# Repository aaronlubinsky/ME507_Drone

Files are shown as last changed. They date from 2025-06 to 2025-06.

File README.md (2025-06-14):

# ME-507 Drone Project



## Overview
This is the documentation for a quadcopter design by Aaron Lubisnky and Dane Carroll. This project was taken on and guided by Cal Poly's ME507 course (Graduate Mechanical Control Systems Design) and instructed by lecturer, Charlie Refvem.

The drone has a custom designed and 3D printed frame. It has been designed to operate using a custom PCB including an onboard STM2F411CEU6 MCU and BNO055 IMU. Though, currently uses a Blackpill development board and Bosch BN055 development board due to in house PCB manufacturing failures. The arming sequence is tailored towards ReadyTosky ESCs and the bluetooth module (HC05) is intended to interact with a PC running a custom python script for drone control and plotting blackbox data.

## Hardware
The drone’s frame, fabricated using 3D printing technology, is lightweight yet robust, providing a stable platform for four brushless motors, each controlled by an individual ReadyToSky electronic speed controller. Power is supplied by a 3s or 4s LiPo battery, distributed through a 4-channel power distribution board to ensure consistent voltage delivery to all components. At the core of the electronics system is an STM32F411 development board (Blackpill), which serves as the primary microcontroller for processing sensor data and executing control algorithms. Orientation sensing is achieved using an Adafruit BNO055 IMU module, which provides 9-axis data (accelerometer, gyroscope, and magnetometer) in fusion mode for accurate roll, pitch, and yaw measurements. Wireless communication is enabled by an HC-05 Bluetooth module, allowing the drone to receive commands from a ground station and transmit blackbox data for real-time monitoring. Status LEDs are integrated to provide visual feedback on the drone’s operational state, such as arming status and error conditions. While the current setup relies on development boards due to PCB manufacturing issues, the design is optimized for a future transition to a custom PCB integrating the STM32F411CEU6 and BNO055, which will reduce size, weight, and potential points of failure.

**Hardware Components:**
- STM32F4 Development Board
- BNO055 IMU Module
- HC05 Bluetooth Module
- 4x Electronic Speed Controllers (ESCs)
- 4x 3 Phase Brushless Motors
- 4-channel Power Distribution Board
- 3s/4s Battery
- Status LEDs

## Software Implementation
The software for the ME-507 Drone Project is a sophisticated flight control system that integrates real-time sensor processing, control algorithms, and wireless communication. The core of the system runs on the STM32F411 development board, utilizing a finite state machine to manage the drone’s operational states, including initialization, sensor calibration, ESC arming, PID control updates, and blackbox data transmission. The flight control is implemented using a 3-axis PID control loop, with independent controllers for roll, pitch, and yaw to maintain stable flight. The BNO055 IMU operates in fusion mode, combining accelerometer, gyroscope, and magnetometer data to provide accurate orientation measurements. Motor control is achieved by generating PWM signals using the STM32’s hardware timers, ensuring precise and responsive adjustments to the brushless motors. Commands are received wirelessly from an Xbox controller via the HC-05 Bluetooth module, with a custom Python script running on a PC ground station parsing joystick inputs and mapping them to setpoints for angle (roll, pitch, yaw) and throttle. This Python script also handles blackbox data logging, enabling post-flight analysis of flight dynamics. The software is designed for modularity, allowing for easy integration of advanced control algorithms or additional sensors in future iterations. 

## Modeling and Tuning


The control system design for the ME-507 Drone Project relied on a dynamic model of the quadcopter to inform the tuning of its PID controllers. The PID tuning process involved a combination of analytical and empirical methods to balance responsiveness and stability. Initial tuning parameters were derived from the dynamic model, focusing on the roll and pitch dynamics, which were tested independently using step-response experiments. These tests involved applying controlled inputs to the drone and measuring its response via the BNO055 IMU, with data logged for pitch, roll, and yaw angles. The logged data was visualized using the Python ground station software, allowing the team to analyze overshoot, settling time, and steady-state error. Iterative tuning was performed by adjusting the proportional, integral, and derivative gains to minimize oscillations and improve tracking performance. 



## Documentation
The complete codebase is documented using Doxygen. Visit the hosted documentation at:

[aaronlubinsky.github.io/ME507_Drone](https://aaronlubinsky.github.io/ME507_Drone/html/index.html)

## Future Improvements
To advance this project, several key improvements are planned to enhance its functionality, compactness, and performance. A primary goal is transitioning from the current Blackpill development board and Bosch BNO055 development board to a custom-designed PCB integrating the STM32F411CEU6 microcontroller and BNO055 IMU. This will streamline the electronics, reduce weight, and improve reliability by eliminating the dependency on external development boards, addressing the challenges faced with in-house PCB manufacturing failures. Additionally, the Python-based ground station software will be enhanced to include a more robust user interface, featuring real-time plotting of critical flight parameters such as orientation, throttle, and control effort, alongside interactive tuning capabilities for PID gains. Another potential upgrade would be integrating a more robust wireless communication protocol, such as Wi-Fi or a dedicated RF module, to replace the HC-05 Bluetooth module, which would increase range and data throughput.

## Acknowledgments
We thank Lecturer Charlie Refvem for his guidance and Cal Poly's ME-507 course for providing the framework to develop this project.

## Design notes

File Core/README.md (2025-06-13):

# ME-507 Drone Project



## Overview
This is the documentation for a quadcopter design by Aaron Lubisnky and Dane Carroll. This project was taken on and guided by Cal Poly's ME507 course (Graduate Mechanical Control Systems Design) and instructed by lecturer, Charlie Refvem.

The drone has a custom designed and 3D printed frame. It has been designed to operate using a custom PCB including an onboard STM2F411CEU6 MCU and BNO055 IMU. Though, currently uses a Blackpill development board and Bosch BN055 development board due to in house PCB manufacturing failures. The arming sequence is tailored towards ReadyTosky ESCs and the bluetooth module (HC05) is intended to interact with a PC running a custom python script for drone control and plotting blackbox data.

## Hardware
The drone consists of a custom electronics system powered by an STM32F411 development board. It uses a 3D-printed frame to house four brushless motors, ESCs, a power distribution board, and a LiPo battery. A 9-axis IMU is used for orientation sensing, and an HC-05 Bluetooth module allows wireless communication. 

**Hardware Components:**
- STM32F4 Development Board
- BNO055 IMU Module
- HC05 Bluetooth Module
- 4x Electronic Speed Controllers (ESCs)
- 4x 3 Phase Brushless Motors
- 4-channel Power Distribution Board
- 3s/4s Battery
- Status LEDs

## Software Implementation
The flight control system is built using a 3-axis PID loop, with separate PID controllers for roll, pitch, and yaw. Commands are received wirelessly from an Xbox controller via Bluetooth, with a Python script parsing joystick input and mapping it to setpoints for angle and throttle. The STM32’s main loop is structured as a finite state machine with stages for initialization, calibration, ESC arming, PID updates, and sending blackbox data. Orientation measurements are handled using the BNO055 9 axis IMU in fusion mode. Motor outputs are updated every control cycle, with PWM signals generated using STM32 timers. 

## Modeling and Tuning
[Insert Image of Block Diagram]

A dynamic model of the drone was used to derive tuning parameters for the PID loops. Control effort and responsiveness were balanced using empirical tuning and log analysis. Pitch and roll dynamics were first tuned independently using step-response testing. Sensor data such as pitch, roll, and yaw angles were logged and plotted to visualize control performance. This allowed iterative tuning to reduce overshoot and steady-state error.



## Documentation
The complete codebase is documented using Doxygen. Visit the hosted documentation at:

https://aaronlubinsky.github.io/ME507_Drone/

## Future Improvements
Transition to the custom PCB with integrated STM32F411CEU6 and BNO055 for a compact design.
Enhance Python ground station software with real-time plotting and tuning interfaces.
Implement advanced control algorithms (e.g., model predictive control) for improved stability.
To advance this project, several key improvements are planned to enhance its functionality, compactness, and performance. A primary goal is transitioning from the current Blackpill development board and Bosch BNO055 development board to a custom-designed PCB integrating the STM32F411CEU6 microcontroller and BNO055 IMU. This will streamline the electronics, reduce weight, and improve reliability by eliminating the dependency on external development boards, addressing the challenges faced with in-house PCB manufacturing failures. Additionally, the Python-based ground station software will be enhanced to include a more robust user interface, featuring real-time plotting of critical flight parameters such as orientation, throttle, and control effort, alongside interactive tuning capabilities for PID gains. Another potential upgrade would be integrating a more robust wireless communication protocol, such as Wi-Fi or a dedicated RF module, to replace the HC-05 Bluetooth module, which would increase range and data throughput.

## Acknowledgments
We thank Lecturer Charlie Refvem for his guidance and Cal Poly's ME-507 course for providing the framework to develop this project.

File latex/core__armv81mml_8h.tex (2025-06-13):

\doxysection{Drivers/\+CMSIS/\+Include/core\+\_\+armv81mml.h File Reference}
\hypertarget{core__armv81mml_8h}{}\label{core__armv81mml_8h}\index{Drivers/CMSIS/Include/core\_armv81mml.h@{Drivers/CMSIS/Include/core\_armv81mml.h}}

CMSIS Armv8.\+1-\/M Mainline Core Peripheral Access Layer Header File.  

{\ttfamily \#include $<$stdint.\+h$>$}\newline
{\ttfamily \#include "{}cmsis\+\_\+version.\+h"{}}\newline
{\ttfamily \#include "{}cmsis\+\_\+compiler.\+h"{}}\newline
{\ttfamily \#include "{}mpu\+\_\+armv8.\+h"{}}\newline
\doxysubsubsection*{Classes}
\begin{DoxyCompactItemize}
\item 
union \mbox{\hyperlink{union_a_p_s_r___type}{APSR\+\_\+\+Type}}
\begin{DoxyCompactList}\small\item\em Union type to access the Application Program Status Register (APSR). \end{DoxyCompactList}\item 
union \mbox{\hyperlink{union_i_p_s_r___type}{IPSR\+\_\+\+Type}}
\begin{DoxyCompactList}\small\item\em Union type to access the Interrupt Program Status Register (IPSR). \end{DoxyCompactList}\item 
union \mbox{\hyperlink{unionx_p_s_r___type}{x\+PSR\+\_\+\+Type}}
\begin{DoxyCompactList}\small\item\em Union type to access the Special-\/\+Purpose Program Status Registers (x\+PSR). \end{DoxyCompactList}\item 
union \mbox{\hyperlink{union_c_o_n_t_r_o_l___type}{CONTROL\+\_\+\+Type}}
\begin{DoxyCompactList}\small\item\em Union type to access the Control Registers (CONTROL). \end{DoxyCompactList}\item 
struct \mbox{\hyperlink{struct_n_v_i_c___type}{NVIC\+\_\+\+Type}}
\begin{DoxyCompactList}\small\item\em Structure type to access the Nested Vectored Interrupt Controller (NVIC). \end{DoxyCompactList}\item 
struct \mbox{\hyperlink{struct_s_c_b___type}{SCB\+\_\+\+Type}}
\begin{DoxyCompactList}\small\item\em Structure type to access the System Control Block (SCB). \end{DoxyCompactList}\item 
struct \mbox{\hyperlink{struct_s_cn_s_c_b___type}{SCn\+SCB\+\_\+\+Type}}
\begin{DoxyCompactList}\small\item\em Structure type to access the System Control and ID Register not in the SCB. \end{DoxyCompactList}\item 
struct \mbox{\hyperlink{struct_sys_tick___type}{Sys\+Tick\+\_\+\+Type}}
\begin{DoxyCompactList}\small\item\em Structure type to access the System Timer (Sys\+Tick). \end{DoxyCompactList}\item 
struct \mbox{\hyperlink{struct_i_t_m___type}{ITM\+\_\+\+Type}}
\begin{DoxyCompactList}\small\item\em Structure type to access the Instrumentation Trace Macrocell Register (ITM). \end{DoxyCompactList}\item 
struct \mbox{\hyperlink{struct_d_w_t___type}{DWT\+\_\+\+Type}}
\begin{DoxyCompactList}\small\item\em Structure type to access the Data Watchpoint and Trace Register (DWT). \end{DoxyCompactList}\item 
struct \mbox{\hyperlink{struct_t_p_i___type}{TPI\+\_\+\+Type}}
\begin{DoxyCompactList}\small\item\em Structure type to access the Trace Port Interface Register (TPI). \end{DoxyCompactList}\item 
struct \mbox{\hyperlink{struct_m_p_u___type}{MPU\+\_\+\+Type}}
\begin{DoxyCompactList}\small\item\em Structure type to access the Memory Protection Unit (MPU). \end{DoxyCompactList}\item 
struct \mbox{\hyperlink{struct_f_p_u___type}{FPU\+\_\+\+Type}}
\begin{DoxyCompactList}\small\item\em Structure type to access the Floating Point Unit (FPU). \end{DoxyCompactList}\item 
struct \mbox{\hyperlink{struct_core_debug___type}{Core\+Debug\+\_\+\+Type}}
\begin{DoxyCompactList}\small\item\em Structure type to access the Core Debug Register (Core\+Debug). \end{DoxyCompactList}\item 
struct \mbox{\hyperlink{struct_d_c_b___type}{DCB\+\_\+\+Type}}
\begin{DoxyCompactList}\small\item\em Structure type to access the Debug Control Block Registers (DCB). \end{DoxyCompactList}\item 
struct \mbox{\hyperlink{struct_d_i_b___type}{DIB\+\_\+\+Type}}
\begin{DoxyCompactList}\small\item\em Structure type to access the Debug Identification Block Registers (DIB). \end{DoxyCompactList}\end{DoxyCompactItemize}
\doxysubsubsection*{Macros}
\begin{DoxyCompactItemize}
\item 
\Hypertarget{core__armv81mml_8h_a6e3093e3f8f78406fa3b2428052ab8e7}\label{core__armv81mml_8h_a6e3093e3f8f78406fa3b2428052ab8e7} 
\#define {\bfseries \+\_\+\+\_\+\+CORE\+\_\+\+ARMV81\+MML\+\_\+\+H\+\_\+\+GENERIC}
\end{DoxyCompactItemize}
\textbf{ }\par
\begin{DoxyCompactItemize}
\item 
\#define \mbox{\hyperlink{group___c_m_s_i_s___c_o_r_e_gac469528d210043c7bd3f12f0e6824766}{APSR\+\_\+\+N\+\_\+\+Pos}}~31U
\item 
\#define \mbox{\hyperlink{group___c_m_s_i_s___c_o_r_e_gadbc2cf55a026f661b53fadfcf822cef1}{APSR\+\_\+\+N\+\_\+\+Msk}}~(1UL $<$$<$ \mbox{\hyperlink{group___c_m_s_i_s___c_o_r_e_gac469528d210043c7bd3f12f0e6824766}{APSR\+\_\+\+N\+\_\+\+Pos}})
\item 
\#define \mbox{\hyperlink{group___c_m_s_i_s___c_o_r_e_ga3661286d108b1aca308d7445685eae3a}{APSR\+\_\+\+Z\+\_\+\+Pos}}~30U
\item 
\#define \mbox{\hyperlink{group___c_m_s_i_s___c_o_r_e_ga1deb4d1aa72bb83d1f79329406f15711}{APSR\+\_\+\+Z\+\_\+\+Msk}}~(1UL $<$$<$ \mbox{\hyperlink{group___c_m_s_i_s___c_o_r_e_ga3661286d108b1aca308d7445685eae3a}{APSR\+\_\+\+Z\+\_\+\+Pos}})
\item 
\#define \mbox{\hyperlink{group___c_m_s_i_s___c_o_r_e_ga6cf72aa6f09a168f9e5beda1a4a887b9}{APSR\+\_\+\+C\+\_\+\+Pos}}~29U
\item 
\#define \mbox{\hyperlink{group___c_m_s_i_s___c_o_r_e_ga6d47803fbad455bc10bd1ce59f2f335d}{APSR\+\_\+\+C\+\_\+\+Msk}}~(1UL $<$$<$ \mbox{\hyperlink{group___c_m_s_i_s___c_o_r_e_ga6cf72aa6f09a168f9e5beda1a4a887b9}{APSR\+\_\+\+C\+\_\+\+Pos}})
\item 
\#define \mbox{\hyperlink{group___c_m_s_i_s___c_o_r_e_gac62830f67679ccd11658c4172c3e6ea7}{APSR\+\_\+\+V\+\_\+\+Pos}}~28U
\item 
\#define \mbox{\hyperlink{group___c_m_s_i_s___c_o_r_e_ga33305d6701356bff6890b315fe8b5489}{APSR\+\_\+\+V\+\_\+\+Msk}}~(1UL $<$$<$ \mbox{\hyperlink{group___c_m_s_i_s___c_o_r_e_gac62830f67679ccd11658c4172c3e6ea7}{APSR\+\_\+\+V\+\_\+\+Pos}})
\item 
\#define \mbox{\hyperlink{group___c_m_s_i_s___c_o_r_e_ga298749e176f12827328bb7b92a6b2411}{APSR\+\_\+\+Q\+\_\+\+Pos}}~27U
\item 
\#define \mbox{\hyperlink{group___c_m_s_i_s___c_o_r_e_ga90ffd4ec4149c2f5dd7747c1533fb002}{APSR\+\_\+\+Q\+\_\+\+Msk}}~(1UL $<$$<$ \mbox{\hyperlink{group___c_m_s_i_s___c_o_r_e_ga298749e176f12827328bb7b92a6b2411}{APSR\+\_\+\+Q\+\_\+\+Pos}})
\item 
\#define \mbox{\hyperlink{group___c_m_s_i_s___c_o_r_e_ga722cb42b5c75af3e8909fac6fd40dfdc}{APSR\+\_\+\+GE\+\_\+\+Pos}}~16U
\item 
\#define \mbox{\hyperlink{group___c_m_s_i_s___c_o_r_e_ga8a3ecbc0ea2029462b0f4ce50e227db1}{APSR\+\_\+\+GE\+\_\+\+Msk}}~(0x\+FUL $<$$<$ \mbox{\hyperlink{group___c_m_s_i_s___c_o_r_e_ga722cb42b5c75af3e8909fac6fd40dfdc}{APSR\+\_\+\+GE\+\_\+\+Pos}})
\item 
\#define \mbox{\hyperlink{group___c_m_s_i_s___c_o_r_e_ga0e34027584d02c43811ae908a5ca9adf}{IPSR\+\_\+\+ISR\+\_\+\+Pos}}~0U
\item 
\#define \mbox{\hyperlink{group___c_m_s_i_s___c_o_r_e_gaf013a4579a64d1f21f56ea9f1b33ab56}{IPSR\+\_\+\+ISR\+\_\+\+Msk}}~(0x1\+FFUL /\texorpdfstring{$\ast$}{*}$<$$<$ \mbox{\hyperlink{group___c_m_s_i_s___c_o_r_e_ga0e34027584d02c43811ae908a5ca9adf}{IPSR\+\_\+\+ISR\+\_\+\+Pos}}\texorpdfstring{$\ast$}{*}/)
\item 
\#define \mbox{\hyperlink{group___c_m_s_i_s___c_o_r_e_ga031eb1b8ebcdb3d602d0b9f2ec82a7ae}{x\+PSR\+\_\+\+N\+\_\+\+Pos}}~31U
\item 
\#define \mbox{\hyperlink{group___c_m_s_i_s___c_o_r_e_gaf600f4ff41b62cf2f3b0a59b6d2e93d6}{x\+PSR\+\_\+\+N\+\_\+\+Msk}}~(1UL $<$$<$ \mbox{\hyperlink{group___c_m_s_i_s___c_o_r_e_ga031eb1b8ebcdb3d602d0b9f2ec82a7ae}{x\+PSR\+\_\+\+N\+\_\+\+Pos}})
\item 
\#define \mbox{\hyperlink{group___c_m_s_i_s___c_o_r_e_ga5869dd608eea73c80f0567d781d2230b}{x\+PSR\+\_\+\+Z\+\_\+\+Pos}}~30U
\item 
\#define \mbox{\hyperlink{group___c_m_s_i_s___c_o_r_e_ga907599209fba99f579778e662021c4f2}{x\+PSR\+\_\+\+Z\+\_\+\+Msk}}~(1UL $<$$<$ \mbox{\hyperlink{group___c_m_s_i_s___c_o_r_e_ga5869dd608eea73c80f0567d781d2230b}{x\+PSR\+\_\+\+Z\+\_\+\+Pos}})
\item 
\#define \mbox{\hyperlink{group___c_m_s_i_s___c_o_r_e_ga14adb79b91f6634b351a1b57394e2db6}{x\+PSR\+\_\+\+C\+\_\+\+Pos}}~29U
\item 
\#define \mbox{\hyperlink{group___c_m_s_i_s___c_o_r_e_ga21e2497255d380f956ca0f48d11d0775}{x\+PSR\+\_\+\+C\+\_\+\+Msk}}~(1UL $<$$<$ \mbox{\hyperlink{group___c_m_s_i_s___c_o_r_e_ga14adb79b91f6634b351a1b57394e2db6}{x\+PSR\+\_\+\+C\+\_\+\+Pos}})
\item 
\#define \mbox{\hyperlink{group___c_m_s_i_s___c_o_r_e_gae0cfbb394490db402623d97e6a979e00}{x\+PSR\+\_\+\+V\+\_\+\+Pos}}~28U
\item 
\#define \mbox{\hyperlink{group___c_m_s_i_s___c_o_r_e_gab07f94ed3b6ee695f5af719dc27995c2}{x\+PSR\+\_\+\+V\+\_\+\+Msk}}~(1UL $<$$<$ \mbox{\hyperlink{group___c_m_s_i_s___c_o_r_e_gae0cfbb394490db402623d97e6a979e00}{x\+PSR\+\_\+\+V\+\_\+\+Pos}})
\item 
\#define \mbox{\hyperlink{group___c_m_s_i_s___c_o_r_e_gaabb4178d50676a8f19cf8f727f38ace8}{x\+PSR\+\_\+\+Q\+\_\+\+Pos}}~27U
\item 
\#define \mbox{\hyperlink{group___c_m_s_i_s___c_o_r_e_ga133ac393c38559ae43ac36383e731dd4}{x\+PSR\+\_\+\+Q\+\_\+\+Msk}}~(1UL $<$$<$ \mbox{\hyperlink{group___c_m_s_i_s___c_o_r_e_gaabb4178d50676a8f19cf8f727f38ace8}{x\+PSR\+\_\+\+Q\+\_\+\+Pos}})
\item 
\#define \mbox{\hyperlink{group___c_m_s_i_s___c_o_r_e_gac5be1db1343f776ecd00f0a4ebe70a46}{x\+PSR\+\_\+\+IT\+\_\+\+Pos}}~25U
\item 
\#define \mbox{\hyperlink{group___c_m_s_i_s___c_o_r_e_ga6dc177aab488851bb3b98cf4b420141a}{x\+PSR\+\_\+\+IT\+\_\+\+Msk}}~(3UL $<$$<$ \mbox{\hyperlink{group___c_m_s_i_s___c_o_r_e_gac5be1db1343f776ecd00f0a4ebe70a46}{x\+PSR\+\_\+\+IT\+\_\+\+Pos}})
\item 
\#define \mbox{\hyperlink{group___c_m_s_i_s___c_o_r_e_ga98d801da9a49cda944f52aeae104dd38}{x\+PSR\+\_\+\+T\+\_\+\+Pos}}~24U
\item 
\#define \mbox{\hyperlink{group___c_m_s_i_s___c_o_r_e_ga30ae2111816e82d47636a8d4577eb6ee}{x\+PSR\+\_\+\+T\+\_\+\+Msk}}~(1UL $<$$<$ \mbox{\hyperlink{group___c_m_s_i_s___c_o_r_e_ga98d801da9a49cda944f52aeae104dd38}{x\+PSR\+\_\+\+T\+\_\+\+Pos}})
\item 
\#define \mbox{\hyperlink{group___c_m_s_i_s___c_o_r_e_gae2b0f3def0f378e9f1d10a4c727a064b}{x\+PSR\+\_\+\+GE\+\_\+\+Pos}}~16U
\item 
\#define \mbox{\hyperlink{group___c_m_s_i_s___c_o_r_e_ga967634e605d013e9b07002eca31f7903}{x\+PSR\+\_\+\+GE\+\_\+\+Msk}}~(0x\+FUL $<$$<$ \mbox{\hyperlink{group___c_m_s_i_s___c_o_r_e_gae2b0f3def0f378e9f1d10a4c727a064b}{x\+PSR\+\_\+\+GE\+\_\+\+Pos}})
\item 
\#define \mbox{\hyperlink{group___c_m_s_i_s___c_o_r_e_ga21bff245fb1aef9683f693d9d7bb2233}{x\+PSR\+\_\+\+ISR\+\_\+\+Pos}}~0U
\item 
\#define \mbox{\hyperlink{group___c_m_s_i_s___c_o_r_e_gadf8eed87e0081dfe1ef1c78a0ea91afd}{x\+PSR\+\_\+\+ISR\+\_\+\+Msk}}~(0x1\+FFUL /\texorpdfstring{$\ast$}{*}$<$$<$ \mbox{\hyperlink{group___c_m_s_i_s___c_o_r_e_ga21bff245fb1aef9683f693d9d7bb2233}{x\+PSR\+\_\+\+ISR\+\_\+\+Pos}}\texorpdfstring{$\ast$}{*}/)
\item 
\#define \mbox{\hyperlink{group___c_m_s_i_s___c_o_r_e_gac4eb493f7e00c0b286f6663b2554d5f1}{CONTROL\+\_\+\+SFPA\+\_\+\+Pos}}~3U
\item 
\#define \mbox{\hyperlink{group___c_m_s_i_s___c_o_r_e_gae1af7c6a3a6482a32ae290b66db3a3f8}{CONTROL\+\_\+\+SFPA\+\_\+\+Msk}}~(1UL $<$$<$ \mbox{\hyperlink{group___c_m_s_i_s___c_o_r_e_gac4eb493f7e00c0b286f6663b2554d5f1}{CONTROL\+\_\+\+SFPA\+\_\+\+Pos}})
\item 
\#define \mbox{\hyperlink{group___c_m_s_i_s___c_o_r_e_gac7018b59b07134c5363b33eb94918a58}{CONTROL\+\_\+\+FPCA\+\_\+\+Pos}}~2U
\item 
\#define \mbox{\hyperlink{group___c_m_s_i_s___c_o_r_e_gad20bb0212b2e1864f24af38d93587c79}{CONTROL\+\_\+\+FPCA\+\_\+\+Msk}}~(1UL $<$$<$ \mbox{\hyperlink{group___c_m_s_i_s___c_o_r_e_gac7018b59b07134c5363b33eb94918a58}{CONTROL\+\_\+\+FPCA\+\_\+\+Pos}})
\item 
\#define \mbox{\hyperlink{group___c_m_s_i_s___c_o_r_e_ga07eafc53e609895342c6a530e9d01310}{CONTROL\+\_\+\+SPSEL\+\_\+\+Pos}}~1U
\item 
\#define \mbox{\hyperlink{group___c_m_s_i_s___c_o_r_e_ga70b29840969b06909da21369b0b05b53}{CONTROL\+\_\+\+SPSEL\+\_\+\+Msk}}~(1UL $<$$<$ \mbox{\hyperlink{group___c_m_s_i_s___c_o_r_e_ga07eafc53e609895342c6a530e9d01310}{CONTROL\+\_\+\+SPSEL\+\_\+\+Pos}})
\item 
\#define \mbox{\hyperlink{group___c_m_s_i_s___c_o_r_e_ga51b95bc03ec0d815b459bde0b14a5908}{CONTROL\+\_\+n\+PRIV\+\_\+\+Pos}}~0U
\item 
\#define \mbox{\hyperlink{group___c_m_s_i_s___c_o_r_e_gaef3b20d77acb213338f89ce5e7bc36b0}{CONTROL\+\_\+n\+PRIV\+\_\+\+Msk}}~(1UL /\texorpdfstring{$\ast$}{*}$<$$<$ \mbox{\hyperlink{group___c_m_s_i_s___c_o_r_e_ga51b95bc03ec0d815b459bde0b14a5908}{CONTROL\+\_\+n\+PRIV\+\_\+\+Pos}}\texorpdfstring{$\ast$}{*}/)
\item 
\#define \mbox{\hyperlink{group___c_m_s_i_s___c_o_r_e_ga9eebe495e2e48d302211108837a2b3e8}{NVIC\+\_\+\+STIR\+\_\+\+INTID\+\_\+\+Pos}}~0U
\item 
\#define \mbox{\hyperlink{group___c_m_s_i_s___c_o_r_e_gae4060c4dfcebb08871ca4244176ce752}{NVIC\+\_\+\+STIR\+\_\+\+INTID\+\_\+\+Msk}}~(0x1\+FFUL /\texorpdfstring{$\ast$}{*}$<$$<$ \mbox{\hyperlink{group___c_m_s_i_s___c_o_r_e_ga9eebe495e2e48d302211108837a2b3e8}{NVIC\+\_\+\+STIR\+\_\+\+INTID\+\_\+\+Pos}}\texorpdfstring{$\ast$}{*}/)
\item 
\#define \mbox{\hyperlink{group___c_m_s_i_s___c_o_r_e_ga58686b88f94f789d4e6f429fe1ff58cf}{SCB\+\_\+\+CPUID\+\_\+\+IMPLEMENTER\+\_\+\+Pos}}~24U
\item 
\#define \mbox{\hyperlink{group___c_m_s_i_s___c_o_r_e_ga0932b31faafd47656a03ced75a31d99b}{SCB\+\_\+\+CPUID\+\_\+\+IMPLEMENTER\+\_\+\+Msk}}~(0x\+FFUL $<$$<$ \mbox{\hyperlink{group___c_m_s_i_s___c_o_r_e_ga58686b88f94f789d4e6f429fe1ff58cf}{SCB\+\_\+\+CPUID\+\_\+\+IMPLEMENTER\+\_\+\+Pos}})
\item 
\#define \mbox{\hyperlink{group___c_m_s_i_s___c_o_r_e_ga104462bd0815391b4044a70bd15d3a71}{SCB\+\_\+\+CPUID\+\_\+\+VARIANT\+\_\+\+Pos}}~20U
\item 
\#define \mbox{\hyperlink{group___c_m_s_i_s___c_o_r_e_gad358dfbd04300afc1824329d128b99e8}{SCB\+\_\+\+CPUID\+\_\+\+VARIANT\+\_\+\+Msk}}~(0x\+FUL $<$$<$ \mbox{\hyperlink{group___c_m_s_i_s___c_o_r_e_ga104462bd0815391b4044a70bd15d3a71}{SCB\+\_\+\+CPUID\+\_\+\+VARIANT\+\_\+\+Pos}})
\item 
\#define \mbox{\hyperlink{group___c_m_s_i_s___c_o_r_e_gaf8b3236b08fb8e840efb682645fb0e98}{SCB\+\_\+\+CPUID\+\_\+\+ARCHITECTURE\+\_\+\+Pos}}~16U
\item 
\#define \mbox{\hyperlink{group___c_m_s_i_s___c_o_r_e_gafae4a1f27a927338ae9dc51a0e146213}{SCB\+\_\+\+CPUID\+\_\+\+ARCHITECTURE\+\_\+\+Msk}}~(0x\+FUL $<$$<$ \mbox{\hyperlink{group___c_m_s_i_s___c_o_r_e_gaf8b3236b08fb8e840efb682645fb0e98}{SCB\+\_\+\+CPUID\+\_\+\+ARCHITECTURE\+\_\+\+Pos}})
\item 
\#define \mbox{\hyperlink{group___c_m_s_i_s___c_o_r_e_ga705f68eaa9afb042ca2407dc4e4629ac}{SCB\+\_\+\+CPUID\+\_\+\+PARTNO\+\_\+\+Pos}}~4U
\item 
\#define \mbox{\hyperlink{group___c_m_s_i_s___c_o_r_e_ga98e581423ca016680c238c469aba546d}{SCB\+\_\+\+CPUID\+\_\+\+PARTNO\+\_\+\+Msk}}~(0x\+FFFUL $<$$<$ \mbox{\hyperlink{group___c_m_s_i_s___c_o_r_e_ga705f68eaa9afb042ca2407dc4e4629ac}{SCB\+\_\+\+CPUID\+\_\+\+PARTNO\+\_\+\+Pos}})
\item 
\#define \mbox{\hyperlink{group___c_m_s_i_s___c_o_r_e_ga3c3d9071e574de11fb27ba57034838b1}{SCB\+\_\+\+CPUID\+\_\+\+REVISION\+\_\+\+Pos}}~0U
\item 
\#define \mbox{\hyperlink{group___c_m_s_i_s___c_o_r_e_ga2ec0448b6483f77e7f5d08b4b81d85df}{SCB\+\_\+\+CPUID\+\_\+\+REVISION\+\_\+\+Msk}}~(0x\+FUL /\texorpdfstring{$\ast$}{*}$<$$<$ \mbox{\hyperlink{group___c_m_s_i_s___c_o_r_e_ga3c3d9071e574de11fb27ba57034838b1}{SCB\+\_\+\+CPUID\+\_\+\+REVISION\+\_\+\+Pos}}\texorpdfstring{$\ast$}{*}/)
\item 
\#define \mbox{\hyperlink{group___c_m_s_i_s___c_o_r_e_gac180386fac3a5701e6060084dacd003a}{SCB\+\_\+\+ICSR\+\_\+\+PENDNMISET\+\_\+\+Pos}}~31U
\item 
\#define \mbox{\hyperlink{group___c_m_s_i_s___c_o_r_e_gadb4dbf66078026dedc24e8cb9a21b2b1}{SCB\+\_\+\+ICSR\+\_\+\+PENDNMISET\+\_\+\+Msk}}~(1UL $<$$<$ \mbox{\hyperlink{group___c_m_s_i_s___c_o_r_e_gac180386fac3a5701e6060084dacd003a}{SCB\+\_\+\+ICSR\+\_\+\+PENDNMISET\+\_\+\+Pos}})
\item 
\#define \mbox{\hyperlink{group___c_m_s_i_s___c_o_r_e_ga750d4b52624a46d71356db4ea769573b}{SCB\+\_\+\+ICSR\+\_\+\+NMIPENDSET\+\_\+\+Pos}}~\mbox{\hyperlink{group___c_m_s_i_s___c_o_r_e_gac180386fac3a5701e6060084dacd003a}{SCB\+\_\+\+ICSR\+\_\+\+PENDNMISET\+\_\+\+Pos}}
\item 
\#define \mbox{\hyperlink{group___c_m_s_i_s___c_o_r_e_ga340e3f79e9c3607dee9f2c048b6b22e8}{SCB\+\_\+\+ICSR\+\_\+\+NMIPENDSET\+\_\+\+Msk}}~\mbox{\hyperlink{group___c_m_s_i_s___c_o_r_e_gadb4dbf66078026dedc24e8cb9a21b2b1}{SCB\+\_\+\+ICSR\+\_\+\+PENDNMISET\+\_\+\+Msk}}
\item 
\#define \mbox{\hyperlink{group___c_m_s_i_s___c_o_r_e_gad4c1ddde49ff0d3ed1b843d14d38ebf1}{SCB\+\_\+\+ICSR\+\_\+\+PENDNMICLR\+\_\+\+Pos}}~30U
\item 
\#define \mbox{\hyperlink{group___c_m_s_i_s___c_o_r_e_gace870429ae27601613da7c6f6e53a18f}{SCB\+\_\+\+ICSR\+\_\+\+PENDNMICLR\+\_\+\+Msk}}~(1UL $<$$<$ \mbox{\hyperlink{group___c_m_s_i_s___c_o_r_e_gad4c1ddde49ff0d3ed1b843d14d38ebf1}{SCB\+\_\+\+ICSR\+\_\+\+PENDNMICLR\+\_\+\+Pos}})
\item 
\#define \mbox{\hyperlink{group___c_m_s_i_s___c_o_r_e_gab5ded23d2ab1d5ff7cc7ce746205e9fe}{SCB\+\_\+\+ICSR\+\_\+\+PENDSVSET\+\_\+\+Pos}}~28U
\item 
\#define \mbox{\hyperlink{group___c_m_s_i_s___c_o_r_e_ga1e40d93efb402763c8c00ddcc56724ff}{SCB\+\_\+\+ICSR\+\_\+\+PENDSVSET\+\_\+\+Msk}}~(1UL $<$$<$ \mbox{\hyperlink{group___c_m_s_i_s___c_o_r_e_gab5ded23d2ab1d5ff7cc7ce746205e9fe}{SCB\+\_\+\+ICSR\+\_\+\+PENDSVSET\+\_\+\+Pos}})
\item 
\#define \mbox{\hyperlink{group___c_m_s_i_s___c_o_r_e_gae218d9022288f89faf57187c4d542ecd}{SCB\+\_\+\+ICSR\+\_\+\+PENDSVCLR\+\_\+\+Pos}}~27U
\item 
\#define \mbox{\hyperlink{group___c_m_s_i_s___c_o_r_e_ga4a901ace381d3c1c74ac82b22fae2e1e}{SCB\+\_\+\+ICSR\+\_\+\+PENDSVCLR\+\_\+\+Msk}}~(1UL $<$$<$ \mbox{\hyperlink{group___c_m_s_i_s___c_o_r_e_gae218d9022288f89faf57187c4d542ecd}{SCB\+\_\+\+ICSR\+\_\+\+PENDSVCLR\+\_\+\+Pos}})
\item 
\#define \mbox{\hyperlink{group___c_m_s_i_s___c_o_r_e_ga9dbb3358c6167c9c3f85661b90fb2794}{SCB\+\_\+\+ICSR\+\_\+\+PENDSTSET\+\_\+\+Pos}}~26U
\item 
\#define \mbox{\hyperlink{group___c_m_s_i_s___c_o_r_e_ga7325b61ea0ec323ef2d5c893b112e546}{SCB\+\_\+\+ICSR\+\_\+\+PENDSTSET\+\_\+\+Msk}}~(1UL $<$$<$ \mbox{\hyperlink{group___c_m_s_i_s___c_o_r_e_ga9dbb3358c6167c9c3f85661b90fb2794}{SCB\+\_\+\+ICSR\+\_\+\+PENDSTSET\+\_\+\+Pos}})
\item 
\#define \mbox{\hyperlink{group___c_m_s_i_s___c_o_r_e_gadbe25e4b333ece1341beb1a740168fdc}{SCB\+\_\+\+ICSR\+\_\+\+PENDSTCLR\+\_\+\+Pos}}~25U
\item 
\#define \mbox{\hyperlink{group___c_m_s_i_s___c_o_r_e_gab241827d2a793269d8cd99b9b28c2157}{SCB\+\_\+\+ICSR\+\_\+\+PENDSTCLR\+\_\+\+Msk}}~(1UL $<$$<$ \mbox{\hyperlink{group___c_m_s_i_s___c_o_r_e_gadbe25e4b333ece1341beb1a740168fdc}{SCB\+\_\+\+ICSR\+\_\+\+PENDSTCLR\+\_\+\+Pos}})
\item 
\#define \mbox{\hyperlink{group___c_m_s_i_s___c_o_r_e_ga021591700b2d6a6e332d932efaece42b}{SCB\+\_\+\+ICSR\+\_\+\+STTNS\+\_\+\+Pos}}~24U
\item 
\#define \mbox{\hyperlink{group___c_m_s_i_s___c_o_r_e_ga70404175bcf7f329758829a9888e48c4}{SCB\+\_\+\+ICSR\+\_\+\+STTNS\+\_\+\+Msk}}~(1UL $<$$<$ \mbox{\hyperlink{group___c_m_s_i_s___c_o_r_e_ga021591700b2d6a6e332d932efaece42b}{SCB\+\_\+\+ICSR\+\_\+\+STTNS\+\_\+\+Pos}})
\item 
\#define \mbox{\hyperlink{group___c_m_s_i_s___c_o_r_e_ga11cb5b1f9ce167b81f31787a77e575df}{SCB\+\_\+\+ICSR\+\_\+\+ISRPREEMPT\+\_\+\+Pos}}~23U
\item 
\#define \mbox{\hyperlink{group___c_m_s_i_s___c_o_r_e_gaa966600396290808d596fe96e92ca2b5}{SCB\+\_\+\+ICSR\+\_\+\+ISRPREEMPT\+\_\+\+Msk}}~(1UL $<$$<$ \mbox{\hyperlink{group___c_m_s_i_s___c_o_r_e_ga11cb5b1f9ce167b81f31787a77e575df}{SCB\+\_\+\+ICSR\+\_\+\+ISRPREEMPT\+\_\+\+Pos}})
\item 
\#define \mbox{\hyperlink{group___c_m_s_i_s___c_o_r_e_ga10749d92b9b744094b845c2eb46d4319}{SCB\+\_\+\+ICSR\+\_\+\+ISRPENDING\+\_\+\+Pos}}~22U
\item 
\#define \mbox{\hyperlink{group___c_m_s_i_s___c_o_r_e_ga056d74fd538e5d36d3be1f28d399c877}{SCB\+\_\+\+ICSR\+\_\+\+ISRPENDING\+\_\+\+Msk}}~(1UL $<$$<$ \mbox{\hyperlink{group___c_m_s_i_s___c_o_r_e_ga10749d92b9b744094b845c2eb46d4319}{SCB\+\_\+\+ICSR\+\_\+\+ISRPENDING\+\_\+\+Pos}})
\item 
\#define \mbox{\hyperlink{group___c_m_s_i_s___c_o_r_e_gada60c92bf88d6fd21a8f49efa4a127b8}{SCB\+\_\+\+ICSR\+\_\+\+VECTPENDING\+\_\+\+Pos}}~12U
\item 
\#define \mbox{\hyperlink{group___c_m_s_i_s___c_o_r_e_gacb6992e7c7ddc27a370f62878a21ef72}{SCB\+\_\+\+ICSR\+\_\+\+VECTPENDING\+\_\+\+Msk}}~(0x1\+FFUL $<$$<$ \mbox{\hyperlink{group___c_m_s_i_s___c_o_r_e_gada60c92bf88d6fd21a8f49efa4a127b8}{SCB\+\_\+\+ICSR\+\_\+\+VECTPENDING\+\_\+\+Pos}})
\item 
\#define \mbox{\hyperlink{group___c_m_s_i_s___c_o_r_e_ga403d154200242629e6d2764bfc12a7ec}{SCB\+\_\+\+ICSR\+\_\+\+RETTOBASE\+\_\+\+Pos}}~11U
\item 
\#define \mbox{\hyperlink{group___c_m_s_i_s___c_o_r_e_gaca6fc3f79bb550f64fd7df782ed4a5f6}{SCB\+\_\+\+ICSR\+\_\+\+RETTOBASE\+\_\+\+Msk}}~(1UL $<$$<$ \mbox{\hyperlink{group___c_m_s_i_s___c_o_r_e_ga403d154200242629e6d2764bfc12a7ec}{SCB\+\_\+\+ICSR\+\_\+\+RETTOBASE\+\_\+\+Pos}})
\item 
\#define \mbox{\hyperlink{group___c_m_s_i_s___c_o_r_e_gae4f602c7c5c895d5fb687b71b0979fc3}{SCB\+\_\+\+ICSR\+\_\+\+VECTACTIVE\+\_\+\+Pos}}~0U
\item 
\#define \mbox{\hyperlink{group___c_m_s_i_s___c_o_r_e_ga5533791a4ecf1b9301c883047b3e8396}{SCB\+\_\+\+ICSR\+\_\+\+VECTACTIVE\+\_\+\+Msk}}~(0x1\+FFUL /\texorpdfstring{$\ast$}{*}$<$$<$ \mbox{\hyperlink{group___c_m_s_i_s___c_o_r_e_gae4f602c7c5c895d5fb687b71b0979fc3}{SCB\+\_\+\+ICSR\+\_\+\+VECTACTIVE\+\_\+\+Pos}}\texorpdfstring{$\ast$}{*}/)
\item 
\#define \mbox{\hyperlink{group___c_m_s_i_s___c_o_r_e_gac6a55451ddd38bffcff5a211d29cea78}{SCB\+\_\+\+VTOR\+\_\+\+TBLOFF\+\_\+\+Pos}}~7U
\item 
\#define \mbox{\hyperlink{group___c_m_s_i_s___c_o_r_e_ga75e395ed74042923e8c93edf50f0996c}{SCB\+\_\+\+VTOR\+\_\+\+TBLOFF\+\_\+\+Msk}}~(0x1\+FFFFFFUL $<$$<$ \mbox{\hyperlink{group___c_m_s_i_s___c_o_r_e_gac6a55451ddd38bffcff5a211d29cea78}{SCB\+\_\+\+VTOR\+\_\+\+TBLOFF\+\_\+\+Pos}})
\item 
\#define \mbox{\hyperlink{group___c_m_s_i_s___c_o_r_e_gaaa27c0ba600bf82c3da08c748845b640}{SCB\+\_\+\+AIRCR\+\_\+\+VECTKEY\+\_\+\+Pos}}~16U
\item 
\#define \mbox{\hyperlink{group___c_m_s_i_s___c_o_r_e_ga90c7cf0c490e7ae55f9503a7fda1dd22}{SCB\+\_\+\+AIRCR\+\_\+\+VECTKEY\+\_\+\+Msk}}~(0x\+FFFFUL $<$$<$ \mbox{\hyperlink{group___c_m_s_i_s___c_o_r_e_gaaa27c0ba600bf82c3da08c748845b640}{SCB\+\_\+\+AIRCR\+\_\+\+VECTKEY\+\_\+\+Pos}})
\item 
\#define \mbox{\hyperlink{group___c_m_s_i_s___c_o_r_e_gaec404750ff5ca07f499a3c06b62051ef}{SCB\+\_\+\+AIRCR\+\_\+\+VECTKEYSTAT\+\_\+\+Pos}}~16U
\item 
\#define \mbox{\hyperlink{group___c_m_s_i_s___c_o_r_e_gabacedaefeefc73d666bbe59ece904493}{SCB\+\_\+\+AIRCR\+\_\+\+VECTKEYSTAT\+\_\+\+Msk}}~(0x\+FFFFUL $<$$<$ \mbox{\hyperlink{group___c_m_s_i_s___c_o_r_e_gaec404750ff5ca07f499a3c06b62051ef}{SCB\+\_\+\+AIRCR\+\_\+\+VECTKEYSTAT\+\_\+\+Pos}})
\item 
\#define \mbox{\hyperlink{group___c_m_s_i_s___c_o_r_e_gad31dec98fbc0d33ace63cb1f1a927923}{SCB\+\_\+\+AIRCR\+\_\+\+ENDIANESS\+\_\+\+Pos}}~15U
\item 
\#define \mbox{\hyperlink{group___c_m_s_i_s___c_o_r_e_ga2f571f93d3d4a6eac9a3040756d3d951}{SCB\+\_\+\+AIRCR\+\_\+\+ENDIANESS\+\_\+\+Msk}}~(1UL $<$$<$ \mbox{\hyperlink{group___c_m_s_i_s___c_o_r_e_gad31dec98fbc0d33ace63cb1f1a927923}{SCB\+\_\+\+AIRCR\+\_\+\+ENDIANESS\+\_\+\+Pos}})
\item 
\#define \mbox{\hyperlink{group___c_m_s_i_s___c_o_r_e_ga2590e227eedb35a41044d8fb7feb9037}{SCB\+\_\+\+AIRCR\+\_\+\+PRIS\+\_\+\+Pos}}~14U
\item 
\#define \mbox{\hyperlink{group___c_m_s_i_s___c_o_r_e_ga0032bb51f38e103fc34c2a57e59ada6f}{SCB\+\_\+\+AIRCR\+\_\+\+PRIS\+\_\+\+Msk}}~(1UL $<$$<$ \mbox{\hyperlink{group___c_m_s_i_s___c_o_r_e_ga2590e227eedb35a41044d8fb7feb9037}{SCB\+\_\+\+AIRCR\+\_\+\+PRIS\+\_\+\+Pos}})
\item 
\#define \mbox{\hyperlink{group___c_m_s_i_s___c_o_r_e_ga94e2fc10be4f6065dcb5a7276b40d933}{SCB\+\_\+\+AIRCR\+\_\+\+BFHFNMINS\+\_\+\+Pos}}~13U
\item 
\#define \mbox{\hyperlink{group___c_m_s_i_s___c_o_r_e_gabc24019f3b54b8d2acd23016b2e0c7b9}{SCB\+\_\+\+AIRCR\+\_\+\+BFHFNMINS\+\_\+\+Msk}}~(1UL $<$$<$ \mbox{\hyperlink{group___c_m_s_i_s___c_o_r_e_ga94e2fc10be4f6065dcb5a7276b40d933}{SCB\+\_\+\+AIRCR\+\_\+\+BFHFNMINS\+\_\+\+Pos}})
\item 
\#define \mbox{\hyperlink{group___c_m_s_i_s___c_o_r_e_gaca155deccdeca0f2c76b8100d24196c8}{SCB\+\_\+\+AIRCR\+\_\+\+PRIGROUP\+\_\+\+Pos}}~8U
\item 
\#define \mbox{\hyperlink{group___c_m_s_i_s___c_o_r_e_ga8be60fff03f48d0d345868060dc6dae7}{SCB\+\_\+\+AIRCR\+\_\+\+PRIGROUP\+\_\+\+Msk}}~(7UL $<$$<$ \mbox{\hyperlink{group___c_m_s_i_s___c_o_r_e_gaca155deccdeca0f2c76b8100d24196c8}{SCB\+\_\+\+AIRCR\+\_\+\+PRIGROUP\+\_\+\+Pos}})
\item 
\#define \mbox{\hyperlink{group___c_m_s_i_s___c_o_r_e_ga7e6b3da07caee0726c5aab97ecebc2a5}{SCB\+\_\+\+AIRCR\+\_\+\+SYSRESETREQS\+\_\+\+Pos}}~3U
\item 
\#define \mbox{\hyperlink{group___c_m_s_i_s___c_o_r_e_gaf4b7fe06aaa2e87cdaf25a720dd282a1}{SCB\+\_\+\+AIRCR\+\_\+\+SYSRESETREQS\+\_\+\+Msk}}~(1UL $<$$<$ \mbox{\hyperlink{group___c_m_s_i_s___c_o_r_e_ga7e6b3da07caee0726c5aab97ecebc2a5}{SCB\+\_\+\+AIRCR\+\_\+\+SYSRESETREQS\+\_\+\+Pos}})
\item 
\#define \mbox{\hyperlink{group___c_m_s_i_s___c_o_r_e_gaffb2737eca1eac0fc1c282a76a40953c}{SCB\+\_\+\+AIRCR\+\_\+\+SYSRESETREQ\+\_\+\+Pos}}~2U
\item 
\#define \mbox{\hyperlink{group___c_m_s_i_s___c_o_r_e_gaae1181119559a5bd36e62afa373fa720}{SCB\+\_\+\+AIRCR\+\_\+\+SYSRESETREQ\+\_\+\+Msk}}~(1UL $<$$<$ \mbox{\hyperlink{group___c_m_s_i_s___c_o_r_e_gaffb2737eca1eac0fc1c282a76a40953c}{SCB\+\_\+\+AIRCR\+\_\+\+SYSRESETREQ\+\_\+\+Pos}})
\item 
\#define \mbox{\hyperlink{group___c_m_s_i_s___c_o_r_e_gaa30a12e892bb696e61626d71359a9029}{SCB\+\_\+\+AIRCR\+\_\+\+VECTCLRACTIVE\+\_\+\+Pos}}~1U
\item 
\#define \mbox{\hyperlink{group___c_m_s_i_s___c_o_r_e_ga212c5ab1c1c82c807d30d2307aa8d218}{SCB\+\_\+\+AIRCR\+\_\+\+VECTCLRACTIVE\+\_\+\+Msk}}~(1UL $<$$<$ \mbox{\hyperlink{group___c_m_s_i_s___c_o_r_e_gaa30a12e892bb696e61626d71359a9029}{SCB\+\_\+\+AIRCR\+\_\+\+VECTCLRACTIVE\+\_\+\+Pos}})
\item 
\#define \mbox{\hyperlink{group___c_m_s_i_s___c_o_r_e_ga3bddcec40aeaf3d3a998446100fa0e44}{SCB\+\_\+\+SCR\+\_\+\+SEVONPEND\+\_\+\+Pos}}~4U
\item 
\#define \mbox{\hyperlink{group___c_m_s_i_s___c_o_r_e_gafb98656644a14342e467505f69a997c9}{SCB\+\_\+\+SCR\+\_\+\+SEVONPEND\+\_\+\+Msk}}~(1UL $<$$<$ \mbox{\hyperlink{group___c_m_s_i_s___c_o_r_e_ga3bddcec40aeaf3d3a998446100fa0e44}{SCB\+\_\+\+SCR\+\_\+\+SEVONPEND\+\_\+\+Pos}})
\item 
\#define \mbox{\hyperlink{group___c_m_s_i_s___c_o_r_e_ga28a2c6524329e68f073b64d4fbfaba39}{SCB\+\_\+\+SCR\+\_\+\+SLEEPDEEPS\+\_\+\+Pos}}~3U
\item 
\#define \mbox{\hyperlink{group___c_m_s_i_s___c_o_r_e_ga7bcfa50d03c2b059ea8661f31d46fa06}{SCB\+\_\+\+SCR\+\_\+\+SLEEPDEEPS\+\_\+\+Msk}}~(1UL $<$$<$ \mbox{\hyperlink{group___c_m_s_i_s___c_o_r_e_ga28a2c6524329e68f073b64d4fbfaba39}{SCB\+\_\+\+SCR\+\_\+\+SLEEPDEEPS\+\_\+\+Pos}})
\item 
\#define \mbox{\hyperlink{group___c_m_s_i_s___c_o_r_e_gab304f6258ec03bd9a6e7a360515c3cfe}{SCB\+\_\+\+SCR\+\_\+\+SLEEPDEEP\+\_\+\+Pos}}~2U
\item 
\#define \mbox{\hyperlink{group___c_m_s_i_s___c_o_r_e_ga77c06a69c63f4b3f6ec1032e911e18e7}{SCB\+\_\+\+SCR\+\_\+\+SLEEPDEEP\+\_\+\+Msk}}~(1UL $<$$<$ \mbox{\hyperlink{group___c_m_s_i_s___c_o_r_e_gab304f6258ec03bd9a6e7a360515c3cfe}{SCB\+\_\+\+SCR\+\_\+\+SLEEPDEEP\+\_\+\+Pos}})
\item 
\#define \mbox{\hyperlink{group___c_m_s_i_s___c_o_r_e_ga3680a15114d7fdc1e25043b881308fe9}{SCB\+\_\+\+SCR\+\_\+\+SLEEPONEXIT\+\_\+\+Pos}}~1U
\item 
\#define \mbox{\hyperlink{group___c_m_s_i_s___c_o_r_e_ga50a243e317b9a70781b02758d45b05ee}{SCB\+\_\+\+SCR\+\_\+\+SLEEPONEXIT\+\_\+\+Msk}}~(1UL $<$$<$ \mbox{\hyperlink{group___c_m_s_i_s___c_o_r_e_ga3680a15114d7fdc1e25043b881308fe9}{SCB\+\_\+\+SCR\+\_\+\+SLEEPONEXIT\+\_\+\+Pos}})
\item 
\#define \mbox{\hyperlink{group___c_m_s_i_s___c_o_r_e_ga2a729c850e865d602bbf25852c7d44fe}{SCB\+\_\+\+CCR\+\_\+\+BP\+\_\+\+Pos}}~18U
\item 
\#define \mbox{\hyperlink{group___c_m_s_i_s___c_o_r_e_ga7fac248cabee94546aa9530d27217772}{SCB\+\_\+\+CCR\+\_\+\+BP\+\_\+\+Msk}}~(1UL $<$$<$ \mbox{\hyperlink{group___c_m_s_i_s___c_o_r_e_ga2a729c850e865d602bbf25852c7d44fe}{SCB\+\_\+\+CCR\+\_\+\+BP\+\_\+\+Pos}})
\item 
\#define \mbox{\hyperlink{group___c_m_s_i_s___c_o_r_e_ga33f0f2a0818b2570f3e00b7e79501448}{SCB\+\_\+\+CCR\+\_\+\+IC\+\_\+\+Pos}}~17U
\item 
\#define \mbox{\hyperlink{group___c_m_s_i_s___c_o_r_e_gaf2ff8f5957edac919e28b536aa6c0a59}{SCB\+\_\+\+CCR\+\_\+\+IC\+\_\+\+Msk}}~(1UL $<$$<$ \mbox{\hyperlink{group___c_m_s_i_s___c_o_r_e_ga33f0f2a0818b2570f3e00b7e79501448}{SCB\+\_\+\+CCR\+\_\+\+IC\+\_\+\+Pos}})
\item 
\#define \mbox{\hyperlink{group___c_m_s_i_s___c_o_r_e_gaa1896a99252649cfb96139b56ba87d9b}{SCB\+\_\+\+CCR\+\_\+\+DC\+\_\+\+Pos}}~16U
\item 
\#define \mbox{\hyperlink{group___c_m_s_i_s___c_o_r_e_ga57b3909dff40a9c28ec50991e4202678}{SCB\+\_\+\+CCR\+\_\+\+DC\+\_\+\+Msk}}~(1UL $<$$<$ \mbox{\hyperlink{group___c_m_s_i_s___c_o_r_e_gaa1896a99252649cfb96139b56ba87d9b}{SCB\+\_\+\+CCR\+\_\+\+DC\+\_\+\+Pos}})
\item 
\#define \mbox{\hyperlink{group___c_m_s_i_s___c_o_r_e_ga98372e0d55ce8573350ce36c500e0555}{SCB\+\_\+\+CCR\+\_\+\+STKOFHFNMIGN\+\_\+\+Pos}}~10U
\item 
\#define \mbox{\hyperlink{group___c_m_s_i_s___c_o_r_e_gaf7004d71376738038e912def01c31fe8}{SCB\+\_\+\+CCR\+\_\+\+STKOFHFNMIGN\+\_\+\+Msk}}~(1UL $<$$<$ \mbox{\hyperlink{group___c_m_s_i_s___c_o_r_e_ga98372e0d55ce8573350ce36c500e0555}{SCB\+\_\+\+CCR\+\_\+\+STKOFHFNMIGN\+\_\+\+Pos}})
\item 
\#define \mbox{\hyperlink{group___c_m_s_i_s___c_o_r_e_ga4010a4f9e2a745af1b58abe1f791ebbf}{SCB\+\_\+\+CCR\+\_\+\+BFHFNMIGN\+\_\+\+Pos}}~8U
\item 
\#define \mbox{\hyperlink{group___c_m_s_i_s___c_o_r_e_ga89a28cc31cfc7d52d9d7a8fcc69c7eac}{SCB\+\_\+\+CCR\+\_\+\+BFHFNMIGN\+\_\+\+Msk}}~(1UL $<$$<$ \mbox{\hyperlink{group___c_m_s_i_s___c_o_r_e_ga4010a4f9e2a745af1b58abe1f791ebbf}{SCB\+\_\+\+CCR\+\_\+\+BFHFNMIGN\+\_\+\+Pos}})
\item 
\#define \mbox{\hyperlink{group___c_m_s_i_s___c_o_r_e_gac8d512998bb8cd9333fb7627ddf59bba}{SCB\+\_\+\+CCR\+\_\+\+DIV\+\_\+0\+\_\+\+TRP\+\_\+\+Pos}}~4U
\item 
\#define \mbox{\hyperlink{group___c_m_s_i_s___c_o_r_e_gabb9aeac71b3abd8586d0297070f61dcb}{SCB\+\_\+\+CCR\+\_\+\+DIV\+\_\+0\+\_\+\+TRP\+\_\+\+Msk}}~(1UL $<$$<$ \mbox{\hyperlink{group___c_m_s_i_s___c_o_r_e_gac8d512998bb8cd9333fb7627ddf59bba}{SCB\+\_\+\+CCR\+\_\+\+DIV\+\_\+0\+\_\+\+TRP\+\_\+\+Pos}})
\item 
\#define \mbox{\hyperlink{group___c_m_s_i_s___c_o_r_e_gac4e4928b864ea10fc24dbbc57d976229}{SCB\+\_\+\+CCR\+\_\+\+UNALIGN\+\_\+\+TRP\+\_\+\+Pos}}~3U
\item 
\#define \mbox{\hyperlink{group___c_m_s_i_s___c_o_r_e_ga68c96ad594af70c007923979085c99e0}{SCB\+\_\+\+CCR\+\_\+\+UNALIGN\+\_\+\+TRP\+\_\+\+Msk}}~(1UL $<$$<$ \mbox{\hyperlink{group___c_m_s_i_s___c_o_r_e_gac4e4928b864ea10fc24dbbc57d976229}{SCB\+\_\+\+CCR\+\_\+\+UNALIGN\+\_\+\+TRP\+\_\+\+Pos}})
\item 
\#define \mbox{\hyperlink{group___c_m_s_i_s___c_o_r_e_ga789e41f45f59a8cd455fd59fa7652e5e}{SCB\+\_\+\+CCR\+\_\+\+USERSETMPEND\+\_\+\+Pos}}~1U
\item 
\#define \mbox{\hyperlink{group___c_m_s_i_s___c_o_r_e_ga4cf59b6343ca962c80e1885710da90aa}{SCB\+\_\+\+CCR\+\_\+\+USERSETMPEND\+\_\+\+Msk}}~(1UL $<$$<$ \mbox{\hyperlink{group___c_m_s_i_s___c_o_r_e_ga789e41f45f59a8cd455fd59fa7652e5e}{SCB\+\_\+\+CCR\+\_\+\+USERSETMPEND\+\_\+\+Pos}})
\item 
\#define \mbox{\hyperlink{group___c_m_s_i_s___c_o_r_e_ga2e86fa5b7279235de3a62839e3f147cb}{SCB\+\_\+\+SHCSR\+\_\+\+HARDFAULTPENDED\+\_\+\+Pos}}~21U
\item 
\#define \mbox{\hyperlink{group___c_m_s_i_s___c_o_r_e_gad72747c81f58f73f0610760529697297}{SCB\+\_\+\+SHCSR\+\_\+\+HARDFAULTPENDED\+\_\+\+Msk}}~(1UL $<$$<$ \mbox{\hyperlink{group___c_m_s_i_s___c_o_r_e_ga2e86fa5b7279235de3a62839e3f147cb}{SCB\+\_\+\+SHCSR\+\_\+\+HARDFAULTPENDED\+\_\+\+Pos}})
\item 
\#define \mbox{\hyperlink{group___c_m_s_i_s___c_o_r_e_ga39d60110521af453e9ae55f1a29d2ab4}{SCB\+\_\+\+SHCSR\+\_\+\+SECUREFAULTPENDED\+\_\+\+Pos}}~20U
\item 
\#define \mbox{\hyperlink{group___c_m_s_i_s___c_o_r_e_ga504f2af763a6f491acaba1912d5fe702}{SCB\+\_\+\+SHCSR\+\_\+\+SECUREFAULTPENDED\+\_\+\+Msk}}~(1UL $<$$<$ \mbox{\hyperlink{group___c_m_s_i_s___c_o_r_e_ga39d60110521af453e9ae55f1a29d2ab4}{SCB\+\_\+\+SHCSR\+\_\+\+SECUREFAULTPENDED\+\_\+\+Pos}})
\item 
\#define \mbox{\hyperlink{group___c_m_s_i_s___c_o_r_e_gafccb0c2b386b439ce03fb25ce3392ffc}{SCB\+\_\+\+SHCSR\+\_\+\+SECUREFAULTENA\+\_\+\+Pos}}~19U
\item 
\#define \mbox{\hyperlink{group___c_m_s_i_s___c_o_r_e_ga2bb1374f777b18501bb0c7b7b1a775aa}{SCB\+\_\+\+SHCSR\+\_\+\+SECUREFAULTENA\+\_\+\+Msk}}~(1UL $<$$<$ \mbox{\hyperlink{group___c_m_s_i_s___c_o_r_e_gafccb0c2b386b439ce03fb25ce3392ffc}{SCB\+\_\+\+SHCSR\+\_\+\+SECUREFAULTENA\+\_\+\+Pos}})
\item 
\#define \mbox{\hyperlink{group___c_m_s_i_s___c_o_r_e_gae71949507636fda388ec11d5c2d30b52}{SCB\+\_\+\+SHCSR\+\_\+\+USGFAULTENA\+\_\+\+Pos}}~18U
\item 
\#define \mbox{\hyperlink{group___c_m_s_i_s___c_o_r_e_ga056fb6be590857bbc029bed48b21dd79}{SCB\+\_\+\+SHCSR\+\_\+\+USGFAULTENA\+\_\+\+Msk}}~(1UL $<$$<$ \mbox{\hyperlink{group___c_m_s_i_s___c_o_r_e_gae71949507636fda388ec11d5c2d30b52}{SCB\+\_\+\+SHCSR\+\_\+\+USGFAULTENA\+\_\+\+Pos}})
\item 
\#define \mbox{\hyperlink{group___c_m_s_i_s___c_o_r_e_ga3d32edbe4a5c0335f808cfc19ec7e844}{SCB\+\_\+\+SHCSR\+\_\+\+BUSFAULTENA\+\_\+\+Pos}}~17U
\item 
\#define \mbox{\hyperlink{group___c_m_s_i_s___c_o_r_e_ga43e8cbe619c9980e0d1aacc85d9b9e47}{SCB\+\_\+\+SHCSR\+\_\+\+BUSFAULTENA\+\_\+\+Msk}}~(1UL $<$$<$ \mbox{\hyperlink{group___c_m_s_i_s___c_o_r_e_ga3d32edbe4a5c0335f808cfc19ec7e844}{SCB\+\_\+\+SHCSR\+\_\+\+BUSFAULTENA\+\_\+\+Pos}})
\item 
\#define \mbox{\hyperlink{group___c_m_s_i_s___c_o_r_e_ga685b4564a8760b4506f14ec4307b7251}{SCB\+\_\+\+SHCSR\+\_\+\+MEMFAULTENA\+\_\+\+Pos}}~16U
\item 
\#define \mbox{\hyperlink{group___c_m_s_i_s___c_o_r_e_gaf084424fa1f69bea36a1c44899d83d17}{SCB\+\_\+\+SHCSR\+\_\+\+MEMFAULTENA\+\_\+\+Msk}}~(1UL $<$$<$ \mbox{\hyperlink{group___c_m_s_i_s___c_o_r_e_ga685b4564a8760b4506f14ec4307b7251}{SCB\+\_\+\+SHCSR\+\_\+\+MEMFAULTENA\+\_\+\+Pos}})
\item 
\#define \mbox{\hyperlink{group___c_m_s_i_s___c_o_r_e_ga2f93ec9b243f94cdd3e94b8f0bf43641}{SCB\+\_\+\+SHCSR\+\_\+\+SVCALLPENDED\+\_\+\+Pos}}~15U
\item 
\#define \mbox{\hyperlink{group___c_m_s_i_s___c_o_r_e_ga6095a7acfbad66f52822b1392be88652}{SCB\+\_\+\+SHCSR\+\_\+\+SVCALLPENDED\+\_\+\+Msk}}~(1UL $<$$<$ \mbox{\hyperlink{group___c_m_s_i_s___c_o_r_e_ga2f93ec9b243f94cdd3e94b8f0bf43641}{SCB\+\_\+\+SHCSR\+\_\+\+SVCALLPENDED\+\_\+\+Pos}})
\item 
\#define \mbox{\hyperlink{group___c_m_s_i_s___c_o_r_e_gaa22551e24a72b65f1e817f7ab462203b}{SCB\+\_\+\+SHCSR\+\_\+\+BUSFAULTPENDED\+\_\+\+Pos}}~14U
\item 
\#define \mbox{\hyperlink{group___c_m_s_i_s___c_o_r_e_ga677c23749c4d348f30fb471d1223e783}{SCB\+\_\+\+SHCSR\+\_\+\+BUSFAULTPENDED\+\_\+\+Msk}}~(1UL $<$$<$ \mbox{\hyperlink{group___c_m_s_i_s___c_o_r_e_gaa22551e24a72b65f1e817f7ab462203b}{SCB\+\_\+\+SHCSR\+\_\+\+BUSFAULTPENDED\+\_\+\+Pos}})
\item 
\#define \mbox{\hyperlink{group___c_m_s_i_s___c_o_r_e_gaceb60fe2d8a8cb17fcd1c1f6b5aa924f}{SCB\+\_\+\+SHCSR\+\_\+\+MEMFAULTPENDED\+\_\+\+Pos}}~13U
\item 
\#define \mbox{\hyperlink{group___c_m_s_i_s___c_o_r_e_ga9abc6c2e395f9e5af4ce05fc420fb04c}{SCB\+\_\+\+SHCSR\+\_\+\+MEMFAULTPENDED\+\_\+\+Msk}}~(1UL $<$$<$ \mbox{\hyperlink{group___c_m_s_i_s___c_o_r_e_gaceb60fe2d8a8cb17fcd1c1f6b5aa924f}{SCB\+\_\+\+SHCSR\+\_\+\+MEMFAULTPENDED\+\_\+\+Pos}})
\item 
\#define \mbox{\hyperlink{group___c_m_s_i_s___c_o_r_e_ga3cf03acf1fdc2edc3b047ddd47ebbf87}{SCB\+\_\+\+SHCSR\+\_\+\+USGFAULTPENDED\+\_\+\+Pos}}~12U
\item 
\#define \mbox{\hyperlink{group___c_m_s_i_s___c_o_r_e_ga122b4f732732010895e438803a29d3cc}{SCB\+\_\+\+SHCSR\+\_\+\+USGFAULTPENDED\+\_\+\+Msk}}~(1UL $<$$<$ \mbox{\hyperlink{group___c_m_s_i_s___c_o_r_e_ga3cf03acf1fdc2edc3b047ddd47ebbf87}{SCB\+\_\+\+SHCSR\+\_\+\+USGFAULTPENDED\+\_\+\+Pos}})
\item 
\#define \mbox{\hyperlink{group___c_m_s_i_s___c_o_r_e_gaec9ca3b1213c49e2442373445e1697de}{SCB\+\_\+\+SHCSR\+\_\+\+SYSTICKACT\+\_\+\+Pos}}~11U
\item 
\#define \mbox{\hyperlink{group___c_m_s_i_s___c_o_r_e_gafef530088dc6d6bfc9f1893d52853684}{SCB\+\_\+\+SHCSR\+\_\+\+SYSTICKACT\+\_\+\+Msk}}~(1UL $<$$<$ \mbox{\hyperlink{group___c_m_s_i_s___c_o_r_e_gaec9ca3b1213c49e2442373445e1697de}{SCB\+\_\+\+SHCSR\+\_\+\+SYSTICKACT\+\_\+\+Pos}})
\item 
\#define \mbox{\hyperlink{group___c_m_s_i_s___c_o_r_e_ga9b9fa69ce4c5ce7fe0861dbccfb15939}{SCB\+\_\+\+SHCSR\+\_\+\+PENDSVACT\+\_\+\+Pos}}~10U
\item 
\#define \mbox{\hyperlink{group___c_m_s_i_s___c_o_r_e_gae0e837241a515d4cbadaaae1faa8e039}{SCB\+\_\+\+SHCSR\+\_\+\+PENDSVACT\+\_\+\+Msk}}~(1UL $<$$<$ \mbox{\hyperlink{group___c_m_s_i_s___c_o_r_e_ga9b9fa69ce4c5ce7fe0861dbccfb15939}{SCB\+\_\+\+SHCSR\+\_\+\+PENDSVACT\+\_\+\+Pos}})
\item 
\#define \mbox{\hyperlink{group___c_m_s_i_s___c_o_r_e_ga8b71cf4c61803752a41c96deb00d26af}{SCB\+\_\+\+SHCSR\+\_\+\+MONITORACT\+\_\+\+Pos}}~8U
\item 
\#define \mbox{\hyperlink{group___c_m_s_i_s___c_o_r_e_gaad09b4bc36e9bccccc2e110d20b16e1a}{SCB\+\_\+\+SHCSR\+\_\+\+MONITORACT\+\_\+\+Msk}}~(1UL $<$$<$ \mbox{\hyperlink{group___c_m_s_i_s___c_o_r_e_ga8b71cf4c61803752a41c96deb00d26af}{SCB\+\_\+\+SHCSR\+\_\+\+MONITORACT\+\_\+\+Pos}})
\item 
\#define \mbox{\hyperlink{group___c_m_s_i_s___c_o_r_e_ga977f5176be2bc8b123873861b38bc02f}{SCB\+\_\+\+SHCSR\+\_\+\+SVCALLACT\+\_\+\+Pos}}~7U
\item 
\#define \mbox{\hyperlink{group___c_m_s_i_s___c_o_r_e_ga634c0f69a233475289023ae5cb158fdf}{SCB\+\_\+\+SHCSR\+\_\+\+SVCALLACT\+\_\+\+Msk}}~(1UL $<$$<$ \mbox{\hyperlink{group___c_m_s_i_s___c_o_r_e_ga977f5176be2bc8b123873861b38bc02f}{SCB\+\_\+\+SHCSR\+\_\+\+SVCALLACT\+\_\+\+Pos}})
\item 
\#define \mbox{\hyperlink{group___c_m_s_i_s___c_o_r_e_gabab1177d5e9a6ef204b9fd88551b7e53}{SCB\+\_\+\+SHCSR\+\_\+\+NMIACT\+\_\+\+Pos}}~5U
\item 
\#define \mbox{\hyperlink{group___c_m_s_i_s___c_o_r_e_gae5bb28ebc1feed160c9fff1e163d0ee0}{SCB\+\_\+\+SHCSR\+\_\+\+NMIACT\+\_\+\+Msk}}~(1UL $<$$<$ \mbox{\hyperlink{group___c_m_s_i_s___c_o_r_e_gabab1177d5e9a6ef204b9fd88551b7e53}{SCB\+\_\+\+SHCSR\+\_\+\+NMIACT\+\_\+\+Pos}})
\item 
\#define \mbox{\hyperlink{group___c_m_s_i_s___c_o_r_e_ga9c27422acd12822bd6854bcdf0890179}{SCB\+\_\+\+SHCSR\+\_\+\+SECUREFAULTACT\+\_\+\+Pos}}~4U
\item 
\#define \mbox{\hyperlink{group___c_m_s_i_s___c_o_r_e_ga15864bcf00ceff971f7b8c173673dbbf}{SCB\+\_\+\+SHCSR\+\_\+\+SECUREFAULTACT\+\_\+\+Msk}}~(1UL $<$$<$ \mbox{\hyperlink{group___c_m_s_i_s___c_o_r_e_ga9c27422acd12822bd6854bcdf0890179}{SCB\+\_\+\+SHCSR\+\_\+\+SECUREFAULTACT\+\_\+\+Pos}})
\item 
\#define \mbox{\hyperlink{group___c_m_s_i_s___c_o_r_e_gae06f54f5081f01ed3f6824e451ad3656}{SCB\+\_\+\+SHCSR\+\_\+\+USGFAULTACT\+\_\+\+Pos}}~3U
\item 
\#define \mbox{\hyperlink{group___c_m_s_i_s___c_o_r_e_gab3166103b5a5f7931d0df90949c47dfe}{SCB\+\_\+\+SHCSR\+\_\+\+USGFAULTACT\+\_\+\+Msk}}~(1UL $<$$<$ \mbox{\hyperlink{group___c_m_s_i_s___c_o_r_e_gae06f54f5081f01ed3f6824e451ad3656}{SCB\+\_\+\+SHCSR\+\_\+\+USGFAULTACT\+\_\+\+Pos}})
\item 
\#define \mbox{\hyperlink{group___c_m_s_i_s___c_o_r_e_ga499ec47414b2f668c32ebb28b5889e2c}{SCB\+\_\+\+SHCSR\+\_\+\+HARDFAULTACT\+\_\+\+Pos}}~2U
\item 
\#define \mbox{\hyperlink{group___c_m_s_i_s___c_o_r_e_ga5ae1ba2f88b11967bc8ca980fe411b44}{SCB\+\_\+\+SHCSR\+\_\+\+HARDFAULTACT\+\_\+\+Msk}}~(1UL $<$$<$ \mbox{\hyperlink{group___c_m_s_i_s___c_o_r_e_ga499ec47414b2f668c32ebb28b5889e2c}{SCB\+\_\+\+SHCSR\+\_\+\+HARDFAULTACT\+\_\+\+Pos}})
\item 
\#define \mbox{\hyperlink{group___c_m_s_i_s___c_o_r_e_gaf272760f2df9ecdd8a5fbbd65c0b767a}{SCB\+\_\+\+SHCSR\+\_\+\+BUSFAULTACT\+\_\+\+Pos}}~1U
\item 
\#define \mbox{\hyperlink{group___c_m_s_i_s___c_o_r_e_ga9d7a8b1054b655ad08d85c3c535d4f73}{SCB\+\_\+\+SHCSR\+\_\+\+BUSFAULTACT\+\_\+\+Msk}}~(1UL $<$$<$ \mbox{\hyperlink{group___c_m_s_i_s___c_o_r_e_gaf272760f2df9ecdd8a5fbbd65c0b767a}{SCB\+\_\+\+SHCSR\+\_\+\+BUSFAULTACT\+\_\+\+Pos}})
\item 
\#define \mbox{\hyperlink{group___c_m_s_i_s___c_o_r_e_ga7c856f79a75dcc1d1517b19a67691803}{SCB\+\_\+\+SHCSR\+\_\+\+MEMFAULTACT\+\_\+\+Pos}}~0U
\item 
\#define \mbox{\hyperlink{group___c_m_s_i_s___c_o_r_e_ga9147fd4e1b12394ae26eadf900a023a3}{SCB\+\_\+\+SHCSR\+\_\+\+MEMFAULTACT\+\_\+\+Msk}}~(1UL /\texorpdfstring{$\ast$}{*}$<$$<$ \mbox{\hyperlink{group___c_m_s_i_s___c_o_r_e_ga7c856f79a75dcc1d1517b19a67691803}{SCB\+\_\+\+SHCSR\+\_\+\+MEMFAULTACT\+\_\+\+Pos}}\texorpdfstring{$\ast$}{*}/)
\item 
\#define \mbox{\hyperlink{group___c_m_s_i_s___c_o_r_e_gac8e4197b295c8560e68e2d71285c7879}{SCB\+\_\+\+CFSR\+\_\+\+USGFAULTSR\+\_\+\+Pos}}~16U
\item 
\#define \mbox{\hyperlink{group___c_m_s_i_s___c_o_r_e_ga565807b1a3f31891f1f967d0fa30d03f}{SCB\+\_\+\+CFSR\+\_\+\+USGFAULTSR\+\_\+\+Msk}}~(0x\+FFFFUL $<$$<$ \mbox{\hyperlink{group___c_m_s_i_s___c_o_r_e_gac8e4197b295c8560e68e2d71285c7879}{SCB\+\_\+\+CFSR\+\_\+\+USGFAULTSR\+\_\+\+Pos}})
\item 
\#define \mbox{\hyperlink{group___c_m_s_i_s___c_o_r_e_ga555a24f4f57d199f91d1d1ab7c8c3c8a}{SCB\+\_\+\+CFSR\+\_\+\+BUSFAULTSR\+\_\+\+Pos}}~8U
\item 
\#define \mbox{\hyperlink{group___c_m_s_i_s___c_o_r_e_ga26dc1ddfdc37a6b92597a6f7e498c1d6}{SCB\+\_\+\+CFSR\+\_\+\+BUSFAULTSR\+\_\+\+Msk}}~(0x\+FFUL $<$$<$ \mbox{\hyperlink{group___c_m_s_i_s___c_o_r_e_ga555a24f4f57d199f91d1d1ab7c8c3c8a}{SCB\+\_\+\+CFSR\+\_\+\+BUSFAULTSR\+\_\+\+Pos}})
\item 
\#define \mbox{\hyperlink{group___c_m_s_i_s___c_o_r_e_ga91f41491cec5b5acca3fbc94efbd799e}{SCB\+\_\+\+CFSR\+\_\+\+MEMFAULTSR\+\_\+\+Pos}}~0U
\item 
\#define \mbox{\hyperlink{group___c_m_s_i_s___c_o_r_e_gad46716159a3808c9e7da22067d6bec98}{SCB\+\_\+\+CFSR\+\_\+\+MEMFAULTSR\+\_\+\+Msk}}~(0x\+FFUL /\texorpdfstring{$\ast$}{*}$<$$<$ \mbox{\hyperlink{group___c_m_s_i_s___c_o_r_e_ga91f41491cec5b5acca3fbc94efbd799e}{SCB\+\_\+\+CFSR\+\_\+\+MEMFAULTSR\+\_\+\+Pos}}\texorpdfstring{$\ast$}{*}/)
\item 
\#define \mbox{\hyperlink{group___c_m_s_i_s___c_o_r_e_gaf9a595a3a8e0171473d486b490669165}{SCB\+\_\+\+CFSR\+\_\+\+MMARVALID\+\_\+\+Pos}}~(\mbox{\hyperlink{group___c_m_s_i_s___c_o_r_e_ga91f41491cec5b5acca3fbc94efbd799e}{SCB\+\_\+\+CFSR\+\_\+\+MEMFAULTSR\+\_\+\+Pos}} + 7U)
\item 
\#define \mbox{\hyperlink{group___c_m_s_i_s___c_o_r_e_ga33f17b24b05b0405de908ce185bef5c3}{SCB\+\_\+\+CFSR\+\_\+\+MMARVALID\+\_\+\+Msk}}~(1UL $<$$<$ \mbox{\hyperlink{group___c_m_s_i_s___c_o_r_e_gaf9a595a3a8e0171473d486b490669165}{SCB\+\_\+\+CFSR\+\_\+\+MMARVALID\+\_\+\+Pos}})
\item 
\#define \mbox{\hyperlink{group___c_m_s_i_s___c_o_r_e_ga1390a486a538d1bb8e9661b678e88e39}{SCB\+\_\+\+CFSR\+\_\+\+MLSPERR\+\_\+\+Pos}}~(\mbox{\hyperlink{group___c_m_s_i_s___c_o_r_e_ga91f41491cec5b5acca3fbc94efbd799e}{SCB\+\_\+\+CFSR\+\_\+\+MEMFAULTSR\+\_\+\+Pos}} + 5U)
\item 
\#define \mbox{\hyperlink{group___c_m_s_i_s___c_o_r_e_gac0602ef4ef443ef6ccb1f24d6886661a}{SCB\+\_\+\+CFSR\+\_\+\+MLSPERR\+\_\+\+Msk}}~(1UL $<$$<$ \mbox{\hyperlink{group___c_m_s_i_s___c_o_r_e_ga1390a486a538d1bb8e9661b678e88e39}{SCB\+\_\+\+CFSR\+\_\+\+MLSPERR\+\_\+\+Pos}})
\item 
\#define \mbox{\hyperlink{group___c_m_s_i_s___c_o_r_e_ga76517c60f54396e7cf075876e8af7a62}{SCB\+\_\+\+CFSR\+\_\+\+MSTKERR\+\_\+\+Pos}}~(\mbox{\hyperlink{group___c_m_s_i_s___c_o_r_e_ga91f41491cec5b5acca3fbc94efbd799e}{SCB\+\_\+\+CFSR\+\_\+\+MEMFAULTSR\+\_\+\+Pos}} + 4U)
\item 
\#define \mbox{\hyperlink{group___c_m_s_i_s___c_o_r_e_ga30331822fa13db8ee288173cfbcbbf72}{SCB\+\_\+\+CFSR\+\_\+\+MSTKERR\+\_\+\+Msk}}~(1UL $<$$<$ \mbox{\hyperlink{group___c_m_s_i_s___c_o_r_e_ga76517c60f54396e7cf075876e8af7a62}{SCB\+\_\+\+CFSR\+\_\+\+MSTKERR\+\_\+\+Pos}})
\item 
\#define \mbox{\hyperlink{group___c_m_s_i_s___c_o_r_e_ga9e5bd9bcd654e271a3e78c5c0a39444d}{SCB\+\_\+\+CFSR\+\_\+\+MUNSTKERR\+\_\+\+Pos}}~(\mbox{\hyperlink{group___c_m_s_i_s___c_o_r_e_ga91f41491cec5b5acca3fbc94efbd799e}{SCB\+\_\+\+CFSR\+\_\+\+MEMFAULTSR\+\_\+\+Pos}} + 3U)
\item 
\#define \mbox{\hyperlink{group___c_m_s_i_s___c_o_r_e_ga2d77850270c5ca96e63e456315609876}{SCB\+\_\+\+CFSR\+\_\+\+MUNSTKERR\+\_\+\+Msk}}~(1UL $<$$<$ \mbox{\hyperlink{group___c_m_s_i_s___c_o_r_e_ga9e5bd9bcd654e271a3e78c5c0a39444d}{SCB\+\_\+\+CFSR\+\_\+\+MUNSTKERR\+\_\+\+Pos}})
\item 
\#define \mbox{\hyperlink{group___c_m_s_i_s___c_o_r_e_gaa9c22daf6e72e64259673b55ae095725}{SCB\+\_\+\+CFSR\+\_\+\+DACCVIOL\+\_\+\+Pos}}~(\mbox{\hyperlink{group___c_m_s_i_s___c_o_r_e_ga91f41491cec5b5acca3fbc94efbd799e}{SCB\+\_\+\+CFSR\+\_\+\+MEMFAULTSR\+\_\+\+Pos}} + 1U)
\item 
\#define \mbox{\hyperlink{group___c_m_s_i_s___c_o_r_e_gacd585d5b620c175f80dd99aecbe42bcf}{SCB\+\_\+\+CFSR\+\_\+\+DACCVIOL\+\_\+\+Msk}}~(1UL $<$$<$ \mbox{\hyperlink{group___c_m_s_i_s___c_o_r_e_gaa9c22daf6e72e64259673b55ae095725}{SCB\+\_\+\+CFSR\+\_\+\+DACCVIOL\+\_\+\+Pos}})
\item 
\#define \mbox{\hyperlink{group___c_m_s_i_s___c_o_r_e_ga964f0465dfaca775e31db26e50f395d5}{SCB\+\_\+\+CFSR\+\_\+\+IACCVIOL\+\_\+\+Pos}}~(\mbox{\hyperlink{group___c_m_s_i_s___c_o_r_e_ga91f41491cec5b5acca3fbc94efbd799e}{SCB\+\_\+\+CFSR\+\_\+\+MEMFAULTSR\+\_\+\+Pos}} + 0U)
\item 
\#define \mbox{\hyperlink{group___c_m_s_i_s___c_o_r_e_gac0a8e6525cd6c610f05d99640b40e6b7}{SCB\+\_\+\+CFSR\+\_\+\+IACCVIOL\+\_\+\+Msk}}~(1UL /\texorpdfstring{$\ast$}{*}$<$$<$ \mbox{\hyperlink{group___c_m_s_i_s___c_o_r_e_ga964f0465dfaca775e31db26e50f395d5}{SCB\+\_\+\+CFSR\+\_\+\+IACCVIOL\+\_\+\+Pos}}\texorpdfstring{$\ast$}{*}/)
\item 
\#define \mbox{\hyperlink{group___c_m_s_i_s___c_o_r_e_ga1cdff62f1f5730c14c809fef9009bfbb}{SCB\+\_\+\+CFSR\+\_\+\+BFARVALID\+\_\+\+Pos}}~(\mbox{\hyperlink{group___c_m_s_i_s___c_o_r_e_ga555a24f4f57d199f91d1d1ab7c8c3c8a}{SCB\+\_\+\+CFSR\+\_\+\+BUSFAULTSR\+\_\+\+Pos}} + 7U)
\item 
\#define \mbox{\hyperlink{group___c_m_s_i_s___c_o_r_e_ga56dd2218996bebbf2a38180ae6f9fcf7}{SCB\+\_\+\+CFSR\+\_\+\+BFARVALID\+\_\+\+Msk}}~(1UL $<$$<$ \mbox{\hyperlink{group___c_m_s_i_s___c_o_r_e_ga1cdff62f1f5730c14c809fef9009bfbb}{SCB\+\_\+\+CFSR\+\_\+\+BFARVALID\+\_\+\+Pos}})
\item 
\#define \mbox{\hyperlink{group___c_m_s_i_s___c_o_r_e_gaf9b4a695a4f8d14a17be613423ef30e1}{SCB\+\_\+\+CFSR\+\_\+\+LSPERR\+\_\+\+Pos}}~(\mbox{\hyperlink{group___c_m_s_i_s___c_o_r_e_ga555a24f4f57d199f91d1d1ab7c8c3c8a}{SCB\+\_\+\+CFSR\+\_\+\+BUSFAULTSR\+\_\+\+Pos}} + 5U)
\item 
\#define \mbox{\hyperlink{group___c_m_s_i_s___c_o_r_e_ga8af8c68915f63358325fb4ebc5d7acc1}{SCB\+\_\+\+CFSR\+\_\+\+LSPERR\+\_\+\+Msk}}~(1UL $<$$<$ \mbox{\hyperlink{group___c_m_s_i_s___c_o_r_e_gaf9b4a695a4f8d14a17be613423ef30e1}{SCB\+\_\+\+CFSR\+\_\+\+LSPERR\+\_\+\+Pos}})
\item 
\#define \mbox{\hyperlink{group___c_m_s_i_s___c_o_r_e_ga62a8fe875fb6cc28e0e36ddf27d81a8f}{SCB\+\_\+\+CFSR\+\_\+\+STKERR\+\_\+\+Pos}}~(\mbox{\hyperlink{group___c_m_s_i_s___c_o_r_e_ga555a24f4f57d199f91d1d1ab7c8c3c8a}{SCB\+\_\+\+CFSR\+\_\+\+BUSFAULTSR\+\_\+\+Pos}} + 4U)
\item 
\#define \mbox{\hyperlink{group___c_m_s_i_s___c_o_r_e_ga77076fdfa5941327d4d8f0cb99653872}{SCB\+\_\+\+CFSR\+\_\+\+STKERR\+\_\+\+Msk}}~(1UL $<$$<$ \mbox{\hyperlink{group___c_m_s_i_s___c_o_r_e_ga62a8fe875fb6cc28e0e36ddf27d81a8f}{SCB\+\_\+\+CFSR\+\_\+\+STKERR\+\_\+\+Pos}})
\item 
\#define \mbox{\hyperlink{group___c_m_s_i_s___c_o_r_e_ga7f70b590d3d8f11145e4ff20f7c9f3e8}{SCB\+\_\+\+CFSR\+\_\+\+UNSTKERR\+\_\+\+Pos}}~(\mbox{\hyperlink{group___c_m_s_i_s___c_o_r_e_ga555a24f4f57d199f91d1d1ab7c8c3c8a}{SCB\+\_\+\+CFSR\+\_\+\+BUSFAULTSR\+\_\+\+Pos}} + 3U)
\item 
\#define \mbox{\hyperlink{group___c_m_s_i_s___c_o_r_e_ga2dfce5c289681884651f92377d09380e}{SCB\+\_\+\+CFSR\+\_\+\+UNSTKERR\+\_\+\+Msk}}~(1UL $<$$<$ \mbox{\hyperlink{group___c_m_s_i_s___c_o_r_e_ga7f70b590d3d8f11145e4ff20f7c9f3e8}{SCB\+\_\+\+CFSR\+\_\+\+UNSTKERR\+\_\+\+Pos}})
\item 
\#define \mbox{\hyperlink{group___c_m_s_i_s___c_o_r_e_gaec426f59eb8d75acd48b32953ac154f5}{SCB\+\_\+\+CFSR\+\_\+\+IMPRECISERR\+\_\+\+Pos}}~(\mbox{\hyperlink{group___c_m_s_i_s___c_o_r_e_ga555a24f4f57d199f91d1d1ab7c8c3c8a}{SCB\+\_\+\+CFSR\+\_\+\+BUSFAULTSR\+\_\+\+Pos}} + 2U)
\item 
\#define \mbox{\hyperlink{group___c_m_s_i_s___c_o_r_e_ga6e6b3b643e1c2e14c96f10b42d59fc64}{SCB\+\_\+\+CFSR\+\_\+\+IMPRECISERR\+\_\+\+Msk}}~(1UL $<$$<$ \mbox{\hyperlink{group___c_m_s_i_s___c_o_r_e_gaec426f59eb8d75acd48b32953ac154f5}{SCB\+\_\+\+CFSR\+\_\+\+IMPRECISERR\+\_\+\+Pos}})
\item 
\#define \mbox{\hyperlink{group___c_m_s_i_s___c_o_r_e_gaf4744e87d7f6eddbff803977901d6ad0}{SCB\+\_\+\+CFSR\+\_\+\+PRECISERR\+\_\+\+Pos}}~(\mbox{\hyperlink{group___c_m_s_i_s___c_o_r_e_ga555a24f4f57d199f91d1d1ab7c8c3c8a}{SCB\+\_\+\+CFSR\+\_\+\+BUSFAULTSR\+\_\+\+Pos}} + 1U)
\item 
\#define \mbox{\hyperlink{group___c_m_s_i_s___c_o_r_e_gad8fc0d1f80364470e52d3dcf941f38cc}{SCB\+\_\+\+CFSR\+\_\+\+PRECISERR\+\_\+\+Msk}}~(1UL $<$$<$ \mbox{\hyperlink{group___c_m_s_i_s___c_o_r_e_gaf4744e87d7f6eddbff803977901d6ad0}{SCB\+\_\+\+CFSR\+\_\+\+PRECISERR\+\_\+\+Pos}})
\item 
\#define \mbox{\hyperlink{group___c_m_s_i_s___c_o_r_e_gad01f4e7c1daa67e2ca8eb4411fd80df4}{SCB\+\_\+\+CFSR\+\_\+\+IBUSERR\+\_\+\+Pos}}~(\mbox{\hyperlink{group___c_m_s_i_s___c_o_r_e_ga555a24f4f57d199f91d1d1ab7c8c3c8a}{SCB\+\_\+\+CFSR\+\_\+\+BUSFAULTSR\+\_\+\+Pos}} + 0U)
\item 
\#define \mbox{\hyperlink{group___c_m_s_i_s___c_o_r_e_ga2a0907c95aabc4b9d77c3e28d14a717f}{SCB\+\_\+\+CFSR\+\_\+\+IBUSERR\+\_\+\+Msk}}~(1UL $<$$<$ \mbox{\hyperlink{group___c_m_s_i_s___c_o_r_e_gad01f4e7c1daa67e2ca8eb4411fd80df4}{SCB\+\_\+\+CFSR\+\_\+\+IBUSERR\+\_\+\+Pos}})
\item 
\#define \mbox{\hyperlink{group___c_m_s_i_s___c_o_r_e_gaa8fc61d57be3e94db000367f521aa1fc}{SCB\+\_\+\+CFSR\+\_\+\+DIVBYZERO\+\_\+\+Pos}}~(\mbox{\hyperlink{group___c_m_s_i_s___c_o_r_e_gac8e4197b295c8560e68e2d71285c7879}{SCB\+\_\+\+CFSR\+\_\+\+USGFAULTSR\+\_\+\+Pos}} + 9U)
\item 
\#define \mbox{\hyperlink{group___c_m_s_i_s___c_o_r_e_ga9d91a0850b4962ad1335b2eadac6777e}{SCB\+\_\+\+CFSR\+\_\+\+DIVBYZERO\+\_\+\+Msk}}~(1UL $<$$<$ \mbox{\hyperlink{group___c_m_s_i_s___c_o_r_e_gaa8fc61d57be3e94db000367f521aa1fc}{SCB\+\_\+\+CFSR\+\_\+\+DIVBYZERO\+\_\+\+Pos}})
\item 
\#define \mbox{\hyperlink{group___c_m_s_i_s___c_o_r_e_ga8836da99a7e569d7a5a79ab4eaa85690}{SCB\+\_\+\+CFSR\+\_\+\+UNALIGNED\+\_\+\+Pos}}~(\mbox{\hyperlink{group___c_m_s_i_s___c_o_r_e_gac8e4197b295c8560e68e2d71285c7879}{SCB\+\_\+\+CFSR\+\_\+\+USGFAULTSR\+\_\+\+Pos}} + 8U)
\item 
\#define \mbox{\hyperlink{group___c_m_s_i_s___c_o_r_e_gac7d2aa508a08a2cab97aa8683c87d125}{SCB\+\_\+\+CFSR\+\_\+\+UNALIGNED\+\_\+\+Msk}}~(1UL $<$$<$ \mbox{\hyperlink{group___c_m_s_i_s___c_o_r_e_ga8836da99a7e569d7a5a79ab4eaa85690}{SCB\+\_\+\+CFSR\+\_\+\+UNALIGNED\+\_\+\+Pos}})
\item 
\#define \mbox{\hyperlink{group___c_m_s_i_s___c_o_r_e_ga35d4221dbc3b9ec07aa5eb66d3497d7f}{SCB\+\_\+\+CFSR\+\_\+\+STKOF\+\_\+\+Pos}}~(\mbox{\hyperlink{group___c_m_s_i_s___c_o_r_e_gac8e4197b295c8560e68e2d71285c7879}{SCB\+\_\+\+CFSR\+\_\+\+USGFAULTSR\+\_\+\+Pos}} + 4U)
\item 
\#define \mbox{\hyperlink{group___c_m_s_i_s___c_o_r_e_gae0b3bb3653d904169486e2d4efe4c566}{SCB\+\_\+\+CFSR\+\_\+\+STKOF\+\_\+\+Msk}}~(1UL $<$$<$ \mbox{\hyperlink{group___c_m_s_i_s___c_o_r_e_ga35d4221dbc3b9ec07aa5eb66d3497d7f}{SCB\+\_\+\+CFSR\+\_\+\+STKOF\+\_\+\+Pos}})
\item 
\#define \mbox{\hyperlink{group___c_m_s_i_s___c_o_r_e_ga769b841a38d4e7b8c5e7e74cf0455754}{SCB\+\_\+\+CFSR\+\_\+\+NOCP\+\_\+\+Pos}}~(\mbox{\hyperlink{group___c_m_s_i_s___c_o_r_e_gac8e4197b295c8560e68e2d71285c7879}{SCB\+\_\+\+CFSR\+\_\+\+USGFAULTSR\+\_\+\+Pos}} + 3U)
\item 
\#define \mbox{\hyperlink{group___c_m_s_i_s___c_o_r_e_ga6cbafe22a9550ca20427cd7e2f2bed7f}{SCB\+\_\+\+CFSR\+\_\+\+NOCP\+\_\+\+Msk}}~(1UL $<$$<$ \mbox{\hyperlink{group___c_m_s_i_s___c_o_r_e_ga769b841a38d4e7b8c5e7e74cf0455754}{SCB\+\_\+\+CFSR\+\_\+\+NOCP\+\_\+\+Pos}})
\item 
\#define \mbox{\hyperlink{group___c_m_s_i_s___c_o_r_e_ga526d3cebe0e96962941e5e3a729307c2}{SCB\+\_\+\+CFSR\+\_\+\+INVPC\+\_\+\+Pos}}~(\mbox{\hyperlink{group___c_m_s_i_s___c_o_r_e_gac8e4197b295c8560e68e2d71285c7879}{SCB\+\_\+\+CFSR\+\_\+\+USGFAULTSR\+\_\+\+Pos}} + 2U)
\item 
\#define \mbox{\hyperlink{group___c_m_s_i_s___c_o_r_e_gafd7f0192bfedbde5d313fe7e637f55f1}{SCB\+\_\+\+CFSR\+\_\+\+INVPC\+\_\+\+Msk}}~(1UL $<$$<$ \mbox{\hyperlink{group___c_m_s_i_s___c_o_r_e_ga526d3cebe0e96962941e5e3a729307c2}{SCB\+\_\+\+CFSR\+\_\+\+INVPC\+\_\+\+Pos}})
\item 
\#define \mbox{\hyperlink{group___c_m_s_i_s___c_o_r_e_ga85ecc14a387d790129e9a3fb1312407a}{SCB\+\_\+\+CFSR\+\_\+\+INVSTATE\+\_\+\+Pos}}~(\mbox{\hyperlink{group___c_m_s_i_s___c_o_r_e_gac8e4197b295c8560e68e2d71285c7879}{SCB\+\_\+\+CFSR\+\_\+\+USGFAULTSR\+\_\+\+Pos}} + 1U)
\item 
\#define \mbox{\hyperlink{group___c_m_s_i_s___c_o_r_e_ga8088a459ac3900a43a54f5cd4252484d}{SCB\+\_\+\+CFSR\+\_\+\+INVSTATE\+\_\+\+Msk}}~(1UL $<$$<$ \mbox{\hyperlink{group___c_m_s_i_s___c_o_r_e_ga85ecc14a387d790129e9a3fb1312407a}{SCB\+\_\+\+CFSR\+\_\+\+INVSTATE\+\_\+\+Pos}})
\item 
\#define \mbox{\hyperlink{group___c_m_s_i_s___c_o_r_e_ga28219a6a1ae6b6118ffd1682c362c63d}{SCB\+\_\+\+CFSR\+\_\+\+UNDEFINSTR\+\_\+\+Pos}}~(\mbox{\hyperlink{group___c_m_s_i_s___c_o_r_e_gac8e4197b295c8560e68e2d71285c7879}{SCB\+\_\+\+CFSR\+\_\+\+USGFAULTSR\+\_\+\+Pos}} + 0U)
\item 
\#define \mbox{\hyperlink{group___c_m_s_i_s___c_o_r_e_ga96e201c8da2bd76df35e184f31b89f1e}{SCB\+\_\+\+CFSR\+\_\+\+UNDEFINSTR\+\_\+\+Msk}}~(1UL $<$$<$ \mbox{\hyperlink{group___c_m_s_i_s___c_o_r_e_ga28219a6a1ae6b6118ffd1682c362c63d}{SCB\+\_\+\+CFSR\+\_\+\+UNDEFINSTR\+\_\+\+Pos}})
\item 
\#define \mbox{\hyperlink{group___c_m_s_i_s___c_o_r_e_ga300c90cfb7b35c82b4d44ad16c757ffb}{SCB\+\_\+\+HFSR\+\_\+\+DEBUGEVT\+\_\+\+Pos}}~31U
\item 
\#define \mbox{\hyperlink{group___c_m_s_i_s___c_o_r_e_gababd60e94756bb33929d5e6f25d8dba3}{SCB\+\_\+\+HFSR\+\_\+\+DEBUGEVT\+\_\+\+Msk}}~(1UL $<$$<$ \mbox{\hyperlink{group___c_m_s_i_s___c_o_r_e_ga300c90cfb7b35c82b4d44ad16c757ffb}{SCB\+\_\+\+HFSR\+\_\+\+DEBUGEVT\+\_\+\+Pos}})
\item 
\#define \mbox{\hyperlink{group___c_m_s_i_s___c_o_r_e_gab361e54183a378474cb419ae2a55d6f4}{SCB\+\_\+\+HFSR\+\_\+\+FORCED\+\_\+\+Pos}}~30U
\item 
\#define \mbox{\hyperlink{group___c_m_s_i_s___c_o_r_e_ga6560d97ed043bc01152a7247bafa3157}{SCB\+\_\+\+HFSR\+\_\+\+FORCED\+\_\+\+Msk}}~(1UL $<$$<$ \mbox{\hyperlink{group___c_m_s_i_s___c_o_r_e_gab361e54183a378474cb419ae2a55d6f4}{SCB\+\_\+\+HFSR\+\_\+\+FORCED\+\_\+\+Pos}})
\item 
\#define \mbox{\hyperlink{group___c_m_s_i_s___c_o_r_e_ga77993da8de35adea7bda6a4475f036ab}{SCB\+\_\+\+HFSR\+\_\+\+VECTTBL\+\_\+\+Pos}}~1U
\item 
\#define \mbox{\hyperlink{group___c_m_s_i_s___c_o_r_e_gaac5e289211d0a63fe879a9691cb9e1a9}{SCB\+\_\+\+HFSR\+\_\+\+VECTTBL\+\_\+\+Msk}}~(1UL $<$$<$ \mbox{\hyperlink{group___c_m_s_i_s___c_o_r_e_ga77993da8de35adea7bda6a4475f036ab}{SCB\+\_\+\+HFSR\+\_\+\+VECTTBL\+\_\+\+Pos}})
\item 
\#define \mbox{\hyperlink{group___c_m_s_i_s___c_o_r_e_ga13f502fb5ac673df9c287488c40b0c1d}{SCB\+\_\+\+DFSR\+\_\+\+EXTERNAL\+\_\+\+Pos}}~4U
\item 
\#define \mbox{\hyperlink{group___c_m_s_i_s___c_o_r_e_ga3cba2ec1f588ce0b10b191d6b0d23399}{SCB\+\_\+\+DFSR\+\_\+\+EXTERNAL\+\_\+\+Msk}}~(1UL $<$$<$ \mbox{\hyperlink{group___c_m_s_i_s___c_o_r_e_ga13f502fb5ac673df9c287488c40b0c1d}{SCB\+\_\+\+DFSR\+\_\+\+EXTERNAL\+\_\+\+Pos}})
\item 
\#define \mbox{\hyperlink{group___c_m_s_i_s___c_o_r_e_gad02d3eaf062ac184c18a7889c9b6de57}{SCB\+\_\+\+DFSR\+\_\+\+VCATCH\+\_\+\+Pos}}~3U
\item 
\#define \mbox{\hyperlink{group___c_m_s_i_s___c_o_r_e_gacbb931575c07b324ec793775b7c44d05}{SCB\+\_\+\+DFSR\+\_\+\+VCATCH\+\_\+\+Msk}}~(1UL $<$$<$ \mbox{\hyperlink{group___c_m_s_i_s___c_o_r_e_gad02d3eaf062ac184c18a7889c9b6de57}{SCB\+\_\+\+DFSR\+\_\+\+VCATCH\+\_\+\+Pos}})
\item 
\#define \mbox{\hyperlink{group___c_m_s_i_s___c_o_r_e_gaccf82364c6d0ed7206f1084277b7cc61}{SCB\+\_\+\+DFSR\+\_\+\+DWTTRAP\+\_\+\+Pos}}~2U
\item 
\#define \mbox{\hyperlink{group___c_m_s_i_s___c_o_r_e_ga3f7384b8a761704655fd45396a305663}{SCB\+\_\+\+DFSR\+\_\+\+DWTTRAP\+\_\+\+Msk}}~(1UL $<$$<$ \mbox{\hyperlink{group___c_m_s_i_s___c_o_r_e_gaccf82364c6d0ed7206f1084277b7cc61}{SCB\+\_\+\+DFSR\+\_\+\+DWTTRAP\+\_\+\+Pos}})
\item 
\#define \mbox{\hyperlink{group___c_m_s_i_s___c_o_r_e_gaf28fdce48655f0dcefb383aebf26b050}{SCB\+\_\+\+DFSR\+\_\+\+BKPT\+\_\+\+Pos}}~1U
\item 
\#define \mbox{\hyperlink{group___c_m_s_i_s___c_o_r_e_ga609edf8f50bc49adb51ae28bcecefe1f}{SCB\+\_\+\+DFSR\+\_\+\+BKPT\+\_\+\+Msk}}~(1UL $<$$<$ \mbox{\hyperlink{group___c_m_s_i_s___c_o_r_e_gaf28fdce48655f0dcefb383aebf26b050}{SCB\+\_\+\+DFSR\+\_\+\+BKPT\+\_\+\+Pos}})
\item 
\#define \mbox{\hyperlink{group___c_m_s_i_s___c_o_r_e_gaef4ec28427f9f88ac70a13ae4e541378}{SCB\+\_\+\+DFSR\+\_\+\+HALTED\+\_\+\+Pos}}~0U
\item 
\#define \mbox{\hyperlink{group___c_m_s_i_s___c_o_r_e_ga200bcf918d57443b5e29e8ce552e4bdf}{SCB\+\_\+\+DFSR\+\_\+\+HALTED\+\_\+\+Msk}}~(1UL /\texorpdfstring{$\ast$}{*}$<$$<$ \mbox{\hyperlink{group___c_m_s_i_s___c_o_r_e_gaef4ec28427f9f88ac70a13ae4e541378}{SCB\+\_\+\+DFSR\+\_\+\+HALTED\+\_\+\+Pos}}\texorpdfstring{$\ast$}{*}/)
\item 
\#define \mbox{\hyperlink{group___c_m_s_i_s___c_o_r_e_gaa759ff8b4b16e6a7becf00b1a6005f65}{SCB\+\_\+\+NSACR\+\_\+\+CP11\+\_\+\+Pos}}~11U
\item 
\#define \mbox{\hyperlink{group___c_m_s_i_s___c_o_r_e_gac025b32fd79c75b8d0ca578af1818241}{SCB\+\_\+\+NSACR\+\_\+\+CP11\+\_\+\+Msk}}~(1UL $<$$<$ \mbox{\hyperlink{group___c_m_s_i_s___c_o_r_e_gaa759ff8b4b16e6a7becf00b1a6005f65}{SCB\+\_\+\+NSACR\+\_\+\+CP11\+\_\+\+Pos}})
\item 
\#define \mbox{\hyperlink{group___c_m_s_i_s___c_o_r_e_gafb8add9ee956ce7e68254dd17631770c}{SCB\+\_\+\+NSACR\+\_\+\+CP10\+\_\+\+Pos}}~10U
\item 
\#define \mbox{\hyperlink{group___c_m_s_i_s___c_o_r_e_ga3dc791e9d4bc647f3267dbb20bd531f7}{SCB\+\_\+\+NSACR\+\_\+\+CP10\+\_\+\+Msk}}~(1UL $<$$<$ \mbox{\hyperlink{group___c_m_s_i_s___c_o_r_e_gafb8add9ee956ce7e68254dd17631770c}{SCB\+\_\+\+NSACR\+\_\+\+CP10\+\_\+\+Pos}})
\item 
\#define \mbox{\hyperlink{group___c_m_s_i_s___c_o_r_e_ga384f04641b96d74495e023cca27ed72f}{SCB\+\_\+\+CLIDR\+\_\+\+LOUU\+\_\+\+Pos}}~27U
\item 
\#define \mbox{\hyperlink{group___c_m_s_i_s___c_o_r_e_ga4a2124def29e03f85d8ab6b455f5a174}{SCB\+\_\+\+CLIDR\+\_\+\+LOUU\+\_\+\+Msk}}~(7UL $<$$<$ \mbox{\hyperlink{group___c_m_s_i_s___c_o_r_e_ga384f04641b96d74495e023cca27ed72f}{SCB\+\_\+\+CLIDR\+\_\+\+LOUU\+\_\+\+Pos}})
\item 
\#define \mbox{\hyperlink{group___c_m_s_i_s___c_o_r_e_gad723f01984bb639c77acc9529fa35ea8}{SCB\+\_\+\+CLIDR\+\_\+\+LOC\+\_\+\+Pos}}~24U
\item 
\#define \mbox{\hyperlink{group___c_m_s_i_s___c_o_r_e_ga3accaa1c94b1d7b920a48ffa1b47443b}{SCB\+\_\+\+CLIDR\+\_\+\+LOC\+\_\+\+Msk}}~(7UL $<$$<$ \mbox{\hyperlink{group___c_m_s_i_s___c_o_r_e_gad723f01984bb639c77acc9529fa35ea8}{SCB\+\_\+\+CLIDR\+\_\+\+LOC\+\_\+\+Pos}})
\item 
\#define \mbox{\hyperlink{group___c_m_s_i_s___c_o_r_e_gab3c7f12bf78e1049eeb477a1d48b144f}{SCB\+\_\+\+CTR\+\_\+\+FORMAT\+\_\+\+Pos}}~29U
\item 
\#define \mbox{\hyperlink{group___c_m_s_i_s___c_o_r_e_gaf0303349e35d3777aa3aceae268f1651}{SCB\+\_\+\+CTR\+\_\+\+FORMAT\+\_\+\+Msk}}~(7UL $<$$<$ \mbox{\hyperlink{group___c_m_s_i_s___c_o_r_e_gab3c7f12bf78e1049eeb477a1d48b144f}{SCB\+\_\+\+CTR\+\_\+\+FORMAT\+\_\+\+Pos}})
\item 
\#define \mbox{\hyperlink{group___c_m_s_i_s___c_o_r_e_ga96ba2dac3d22d7892eabb851c052a286}{SCB\+\_\+\+CTR\+\_\+\+CWG\+\_\+\+Pos}}~24U
\item 
\#define \mbox{\hyperlink{group___c_m_s_i_s___c_o_r_e_ga341c1fe0efc63e26a2affebda136da6c}{SCB\+\_\+\+CTR\+\_\+\+CWG\+\_\+\+Msk}}~(0x\+FUL $<$$<$ \mbox{\hyperlink{group___c_m_s_i_s___c_o_r_e_ga96ba2dac3d22d7892eabb851c052a286}{SCB\+\_\+\+CTR\+\_\+\+CWG\+\_\+\+Pos}})
\item 
\#define \mbox{\hyperlink{group___c_m_s_i_s___c_o_r_e_ga7692042fbaab5852ca60f6c2d659f724}{SCB\+\_\+\+CTR\+\_\+\+ERG\+\_\+\+Pos}}~20U
\item 
\#define \mbox{\hyperlink{group___c_m_s_i_s___c_o_r_e_ga02bb1ed5199a32e0ebad001e1b64ac35}{SCB\+\_\+\+CTR\+\_\+\+ERG\+\_\+\+Msk}}~(0x\+FUL $<$$<$ \mbox{\hyperlink{group___c_m_s_i_s___c_o_r_e_ga7692042fbaab5852ca60f6c2d659f724}{SCB\+\_\+\+CTR\+\_\+\+ERG\+\_\+\+Pos}})
\item 
\#define \mbox{\hyperlink{group___c_m_s_i_s___c_o_r_e_gae25b69e6ea66c125f703870adabb0d65}{SCB\+\_\+\+CTR\+\_\+\+DMINLINE\+\_\+\+Pos}}~16U
\item 
\#define \mbox{\hyperlink{group___c_m_s_i_s___c_o_r_e_ga634bb0b270954a68757c86c517de948b}{SCB\+\_\+\+CTR\+\_\+\+DMINLINE\+\_\+\+Msk}}~(0x\+FUL $<$$<$ \mbox{\hyperlink{group___c_m_s_i_s___c_o_r_e_gae25b69e6ea66c125f703870adabb0d65}{SCB\+\_\+\+CTR\+\_\+\+DMINLINE\+\_\+\+Pos}})
\item 
\#define \mbox{\hyperlink{group___c_m_s_i_s___c_o_r_e_ga5be00464e6789da9619947d67d2a1529}{SCB\+\_\+\+CTR\+\_\+\+IMINLINE\+\_\+\+Pos}}~0U
\item 
\#define \mbox{\hyperlink{group___c_m_s_i_s___c_o_r_e_gac62440e20c39b8022279a4a706ef9aa3}{SCB\+\_\+\+CTR\+\_\+\+IMINLINE\+\_\+\+Msk}}~(0x\+FUL /\texorpdfstring{$\ast$}{*}$<$$<$ \mbox{\hyperlink{group___c_m_s_i_s___c_o_r_e_ga5be00464e6789da9619947d67d2a1529}{SCB\+\_\+\+CTR\+\_\+\+IMINLINE\+\_\+\+Pos}}\texorpdfstring{$\ast$}{*}/)
\item 
\#define \mbox{\hyperlink{group___c_m_s_i_s___c_o_r_e_ga4eaf5ef29d920023de2cf53b25d0d56c}{SCB\+\_\+\+CCSIDR\+\_\+\+WT\+\_\+\+Pos}}~31U
\item 
\#define \mbox{\hyperlink{group___c_m_s_i_s___c_o_r_e_ga9089551a75985fa7cf051062ed2d62b9}{SCB\+\_\+\+CCSIDR\+\_\+\+WT\+\_\+\+Msk}}~(1UL $<$$<$ \mbox{\hyperlink{group___c_m_s_i_s___c_o_r_e_ga4eaf5ef29d920023de2cf53b25d0d56c}{SCB\+\_\+\+CCSIDR\+\_\+\+WT\+\_\+\+Pos}})
\item 
\#define \mbox{\hyperlink{group___c_m_s_i_s___c_o_r_e_ga4a32c31034cf30f6fe4dfaa9d0d6a6af}{SCB\+\_\+\+CCSIDR\+\_\+\+WB\+\_\+\+Pos}}~30U
\item 
\#define \mbox{\hyperlink{group___c_m_s_i_s___c_o_r_e_gaa9c0516faf8b9c7ab4151823c48f39b6}{SCB\+\_\+\+CCSIDR\+\_\+\+WB\+\_\+\+Msk}}~(1UL $<$$<$ \mbox{\hyperlink{group___c_m_s_i_s___c_o_r_e_ga4a32c31034cf30f6fe4dfaa9d0d6a6af}{SCB\+\_\+\+CCSIDR\+\_\+\+WB\+\_\+\+Pos}})
\item 
\#define \mbox{\hyperlink{group___c_m_s_i_s___c_o_r_e_ga379743eea011cede0032ecb7812b51e1}{SCB\+\_\+\+CCSIDR\+\_\+\+RA\+\_\+\+Pos}}~29U
\item 
\#define \mbox{\hyperlink{group___c_m_s_i_s___c_o_r_e_gaa77f28cbf94b44c1114a66e05cc43255}{SCB\+\_\+\+CCSIDR\+\_\+\+RA\+\_\+\+Msk}}~(1UL $<$$<$ \mbox{\hyperlink{group___c_m_s_i_s___c_o_r_e_ga379743eea011cede0032ecb7812b51e1}{SCB\+\_\+\+CCSIDR\+\_\+\+RA\+\_\+\+Pos}})
\item 
\#define \mbox{\hyperlink{group___c_m_s_i_s___c_o_r_e_gade432ae0a64858e92fa35c2983fb47a4}{SCB\+\_\+\+CCSIDR\+\_\+\+WA\+\_\+\+Pos}}~28U
\item 
\#define \mbox{\hyperlink{group___c_m_s_i_s___c_o_r_e_ga519ebde5ad64be2098f586bddbc8e898}{SCB\+\_\+\+CCSIDR\+\_\+\+WA\+\_\+\+Msk}}~(1UL $<$$<$ \mbox{\hyperlink{group___c_m_s_i_s___c_o_r_e_gade432ae0a64858e92fa35c2983fb47a4}{SCB\+\_\+\+CCSIDR\+\_\+\+WA\+\_\+\+Pos}})
\item 
\#define \mbox{\hyperlink{group___c_m_s_i_s___c_o_r_e_ga1028d2c238f74d2aa021f53ffbe8d7ab}{SCB\+\_\+\+CCSIDR\+\_\+\+NUMSETS\+\_\+\+Pos}}~13U
\item 
\#define \mbox{\hyperlink{group___c_m_s_i_s___c_o_r_e_ga47d1f01185d7a039334031008386c5a8}{SCB\+\_\+\+CCSIDR\+\_\+\+NUMSETS\+\_\+\+Msk}}~(0x7\+FFFUL $<$$<$ \mbox{\hyperlink{group___c_m_s_i_s___c_o_r_e_ga1028d2c238f74d2aa021f53ffbe8d7ab}{SCB\+\_\+\+CCSIDR\+\_\+\+NUMSETS\+\_\+\+Pos}})
\item 
\#define \mbox{\hyperlink{group___c_m_s_i_s___c_o_r_e_gae67f2f83976b819fb3039fc35cfef0fb}{SCB\+\_\+\+CCSIDR\+\_\+\+ASSOCIATIVITY\+\_\+\+Pos}}~3U
\item 
\#define \mbox{\hyperlink{group___c_m_s_i_s___c_o_r_e_gae093c4c635dad43845967512fa87173a}{SCB\+\_\+\+CCSIDR\+\_\+\+ASSOCIATIVITY\+\_\+\+Msk}}~(0x3\+FFUL $<$$<$ \mbox{\hyperlink{group___c_m_s_i_s___c_o_r_e_gae67f2f83976b819fb3039fc35cfef0fb}{SCB\+\_\+\+CCSIDR\+\_\+\+ASSOCIATIVITY\+\_\+\+Pos}})
\item 
\#define \mbox{\hyperlink{group___c_m_s_i_s___c_o_r_e_ga750388e1509b36d35568a68a7a1e1ff7}{SCB\+\_\+\+CCSIDR\+\_\+\+LINESIZE\+\_\+\+Pos}}~0U
\item 
\#define \mbox{\hyperlink{group___c_m_s_i_s___c_o_r_e_ga07b3bdffe4c289b9c19c70cf698499da}{SCB\+\_\+\+CCSIDR\+\_\+\+LINESIZE\+\_\+\+Msk}}~(7UL /\texorpdfstring{$\ast$}{*}$<$$<$ \mbox{\hyperlink{group___c_m_s_i_s___c_o_r_e_ga750388e1509b36d35568a68a7a1e1ff7}{SCB\+\_\+\+CCSIDR\+\_\+\+LINESIZE\+\_\+\+Pos}}\texorpdfstring{$\ast$}{*}/)
\item 
\#define \mbox{\hyperlink{group___c_m_s_i_s___c_o_r_e_ga8c014c9678bc9072f10459a1e14b973c}{SCB\+\_\+\+CSSELR\+\_\+\+LEVEL\+\_\+\+Pos}}~1U
\item 
\#define \mbox{\hyperlink{group___c_m_s_i_s___c_o_r_e_gaa24e3a6d6960acff3d6949e416046cf0}{SCB\+\_\+\+CSSELR\+\_\+\+LEVEL\+\_\+\+Msk}}~(7UL $<$$<$ \mbox{\hyperlink{group___c_m_s_i_s___c_o_r_e_ga8c014c9678bc9072f10459a1e14b973c}{SCB\+\_\+\+CSSELR\+\_\+\+LEVEL\+\_\+\+Pos}})
\item 
\#define \mbox{\hyperlink{group___c_m_s_i_s___c_o_r_e_ga70e80783c3bd7b11504c63b052b0c0b9}{SCB\+\_\+\+CSSELR\+\_\+\+IND\+\_\+\+Pos}}~0U
\item 
\#define \mbox{\hyperlink{group___c_m_s_i_s___c_o_r_e_ga4e5d98f4d43366cadcc5c3d7ac37228c}{SCB\+\_\+\+CSSELR\+\_\+\+IND\+\_\+\+Msk}}~(1UL /\texorpdfstring{$\ast$}{*}$<$$<$ \mbox{\hyperlink{group___c_m_s_i_s___c_o_r_e_ga70e80783c3bd7b11504c63b052b0c0b9}{SCB\+\_\+\+CSSELR\+\_\+\+IND\+\_\+\+Pos}}\texorpdfstring{$\ast$}{*}/)
\item 
\#define \mbox{\hyperlink{group___c_m_s_i_s___c_o_r_e_gaeb4a916d84d967c1bab8e88800a28984}{SCB\+\_\+\+STIR\+\_\+\+INTID\+\_\+\+Pos}}~0U
\item 
\#define \mbox{\hyperlink{group___c_m_s_i_s___c_o_r_e_ga7b67f900eb9c63b04e67f8fa6ddcd8ed}{SCB\+\_\+\+STIR\+\_\+\+INTID\+\_\+\+Msk}}~(0x1\+FFUL /\texorpdfstring{$\ast$}{*}$<$$<$ \mbox{\hyperlink{group___c_m_s_i_s___c_o_r_e_gaeb4a916d84d967c1bab8e88800a28984}{SCB\+\_\+\+STIR\+\_\+\+INTID\+\_\+\+Pos}}\texorpdfstring{$\ast$}{*}/)
\item 
\#define \mbox{\hyperlink{group___c_m_s_i_s___c_o_r_e_gaa6a2a5e1707c9ef277e67dacd4e247fd}{SCB\+\_\+\+DCISW\+\_\+\+WAY\+\_\+\+Pos}}~30U
\item 
\#define \mbox{\hyperlink{group___c_m_s_i_s___c_o_r_e_gabfe6096a36807e0b7e1d09a06ef1d750}{SCB\+\_\+\+DCISW\+\_\+\+WAY\+\_\+\+Msk}}~(3UL $<$$<$ \mbox{\hyperlink{group___c_m_s_i_s___c_o_r_e_gaa6a2a5e1707c9ef277e67dacd4e247fd}{SCB\+\_\+\+DCISW\+\_\+\+WAY\+\_\+\+Pos}})
\item 
\#define \mbox{\hyperlink{group___c_m_s_i_s___c_o_r_e_gaea6bd5b7d1c47c7db06afdecc6e49281}{SCB\+\_\+\+DCISW\+\_\+\+SET\+\_\+\+Pos}}~5U
\item 
\#define \mbox{\hyperlink{group___c_m_s_i_s___c_o_r_e_gab08fbef94f7d068a7c0217e074c697f9}{SCB\+\_\+\+DCISW\+\_\+\+SET\+\_\+\+Msk}}~(0x1\+FFUL $<$$<$ \mbox{\hyperlink{group___c_m_s_i_s___c_o_r_e_gaea6bd5b7d1c47c7db06afdecc6e49281}{SCB\+\_\+\+DCISW\+\_\+\+SET\+\_\+\+Pos}})
\item 
\#define \mbox{\hyperlink{group___c_m_s_i_s___c_o_r_e_ga6cac2d69791e13af276d8306c796925f}{SCB\+\_\+\+DCCSW\+\_\+\+WAY\+\_\+\+Pos}}~30U
\item 
\#define \mbox{\hyperlink{group___c_m_s_i_s___c_o_r_e_ga8374e67655ac524284c9bb59eb2efa23}{SCB\+\_\+\+DCCSW\+\_\+\+WAY\+\_\+\+Msk}}~(3UL $<$$<$ \mbox{\hyperlink{group___c_m_s_i_s___c_o_r_e_ga6cac2d69791e13af276d8306c796925f}{SCB\+\_\+\+DCCSW\+\_\+\+WAY\+\_\+\+Pos}})
\item 
\#define \mbox{\hyperlink{group___c_m_s_i_s___c_o_r_e_gae93985adc38a127bc8dc909ac58e8fea}{SCB\+\_\+\+DCCSW\+\_\+\+SET\+\_\+\+Pos}}~5U
\item 
\#define \mbox{\hyperlink{group___c_m_s_i_s___c_o_r_e_ga669e16d98c8ea0e66afb04641971d98c}{SCB\+\_\+\+DCCSW\+\_\+\+SET\+\_\+\+Msk}}~(0x1\+FFUL $<$$<$ \mbox{\hyperlink{group___c_m_s_i_s___c_o_r_e_gae93985adc38a127bc8dc909ac58e8fea}{SCB\+\_\+\+DCCSW\+\_\+\+SET\+\_\+\+Pos}})
\item 
\#define \mbox{\hyperlink{group___c_m_s_i_s___c_o_r_e_gaa90bd0b36679219d6a2144eba6eb96cd}{SCB\+\_\+\+DCCISW\+\_\+\+WAY\+\_\+\+Pos}}~30U
\item 
\#define \mbox{\hyperlink{group___c_m_s_i_s___c_o_r_e_gaf2269bbe0bc7705e1da8f5ee0f581054}{SCB\+\_\+\+DCCISW\+\_\+\+WAY\+\_\+\+Msk}}~(3UL $<$$<$ \mbox{\hyperlink{group___c_m_s_i_s___c_o_r_e_gaa90bd0b36679219d6a2144eba6eb96cd}{SCB\+\_\+\+DCCISW\+\_\+\+WAY\+\_\+\+Pos}})
\item 
\#define \mbox{\hyperlink{group___c_m_s_i_s___c_o_r_e_ga525f1bb9849e89b3eafbd53dcd51e296}{SCB\+\_\+\+DCCISW\+\_\+\+SET\+\_\+\+Pos}}~5U
\item 
\#define \mbox{\hyperlink{group___c_m_s_i_s___c_o_r_e_gaf1b0bea5ab77d4ad7d5c21e77ca463ad}{SCB\+\_\+\+DCCISW\+\_\+\+SET\+\_\+\+Msk}}~(0x1\+FFUL $<$$<$ \mbox{\hyperlink{group___c_m_s_i_s___c_o_r_e_ga525f1bb9849e89b3eafbd53dcd51e296}{SCB\+\_\+\+DCCISW\+\_\+\+SET\+\_\+\+Pos}})
\item 
\#define \mbox{\hyperlink{group___c_m_s_i_s___c_o_r_e_ga0777ddf379af50f9ca41d40573bfffc5}{SCn\+SCB\+\_\+\+ICTR\+\_\+\+INTLINESNUM\+\_\+\+Pos}}~0U
\item 
\#define \mbox{\hyperlink{group___c_m_s_i_s___c_o_r_e_ga3efa0f5210051464e1034b19fc7b33c7}{SCn\+SCB\+\_\+\+ICTR\+\_\+\+INTLINESNUM\+\_\+\+Msk}}~(0x\+FUL /\texorpdfstring{$\ast$}{*}$<$$<$ \mbox{\hyperlink{group___c_m_s_i_s___c_o_r_e_ga0777ddf379af50f9ca41d40573bfffc5}{SCn\+SCB\+\_\+\+ICTR\+\_\+\+INTLINESNUM\+\_\+\+Pos}}\texorpdfstring{$\ast$}{*}/)
\item 
\#define \mbox{\hyperlink{group___c_m_s_i_s___c_o_r_e_gadbb65d4a815759649db41df216ed4d60}{Sys\+Tick\+\_\+\+CTRL\+\_\+\+COUNTFLAG\+\_\+\+Pos}}~16U
\item 
\#define \mbox{\hyperlink{group___c_m_s_i_s___c_o_r_e_ga1bf3033ecccf200f59baefe15dbb367c}{Sys\+Tick\+\_\+\+CTRL\+\_\+\+COUNTFLAG\+\_\+\+Msk}}~(1UL $<$$<$ \mbox{\hyperlink{group___c_m_s_i_s___c_o_r_e_gadbb65d4a815759649db41df216ed4d60}{Sys\+Tick\+\_\+\+CTRL\+\_\+\+COUNTFLAG\+\_\+\+Pos}})
\item 
\#define \mbox{\hyperlink{group___c_m_s_i_s___c_o_r_e_ga24fbc69a5f0b78d67fda2300257baff1}{Sys\+Tick\+\_\+\+CTRL\+\_\+\+CLKSOURCE\+\_\+\+Pos}}~2U
\item 
\#define \mbox{\hyperlink{group___c_m_s_i_s___c_o_r_e_gaa41d06039797423a46596bd313d57373}{Sys\+Tick\+\_\+\+CTRL\+\_\+\+CLKSOURCE\+\_\+\+Msk}}~(1UL $<$$<$ \mbox{\hyperlink{group___c_m_s_i_s___c_o_r_e_ga24fbc69a5f0b78d67fda2300257baff1}{Sys\+Tick\+\_\+\+CTRL\+\_\+\+CLKSOURCE\+\_\+\+Pos}})
\item 
\#define \mbox{\hyperlink{group___c_m_s_i_s___c_o_r_e_ga88f45bbb89ce8df3cd2b2613c7b48214}{Sys\+Tick\+\_\+\+CTRL\+\_\+\+TICKINT\+\_\+\+Pos}}~1U
\item 
\#define \mbox{\hyperlink{group___c_m_s_i_s___c_o_r_e_ga95bb984266ca764024836a870238a027}{Sys\+Tick\+\_\+\+CTRL\+\_\+\+TICKINT\+\_\+\+Msk}}~(1UL $<$$<$ \mbox{\hyperlink{group___c_m_s_i_s___c_o_r_e_ga88f45bbb89ce8df3cd2b2613c7b48214}{Sys\+Tick\+\_\+\+CTRL\+\_\+\+TICKINT\+\_\+\+Pos}})
\item 
\#define \mbox{\hyperlink{group___c_m_s_i_s___c_o_r_e_ga0b48cc1e36d92a92e4bf632890314810}{Sys\+Tick\+\_\+\+CTRL\+\_\+\+ENABLE\+\_\+\+Pos}}~0U
\item 
\#define \mbox{\hyperlink{group___c_m_s_i_s___c_o_r_e_ga16c9fee0ed0235524bdeb38af328fd1f}{Sys\+Tick\+\_\+\+CTRL\+\_\+\+ENABLE\+\_\+\+Msk}}~(1UL /\texorpdfstring{$\ast$}{*}$<$$<$ \mbox{\hyperlink{group___c_m_s_i_s___c_o_r_e_ga0b48cc1e36d92a92e4bf632890314810}{Sys\+Tick\+\_\+\+CTRL\+\_\+\+ENABLE\+\_\+\+Pos}}\texorpdfstring{$\ast$}{*}/)
\item 
\#define \mbox{\hyperlink{group___c_m_s_i_s___c_o_r_e_gaf44d10df359dc5bf5752b0894ae3bad2}{Sys\+Tick\+\_\+\+LOAD\+\_\+\+RELOAD\+\_\+\+Pos}}~0U
\item 
\#define \mbox{\hyperlink{group___c_m_s_i_s___c_o_r_e_ga265912a7962f0e1abd170336e579b1b1}{Sys\+Tick\+\_\+\+LOAD\+\_\+\+RELOAD\+\_\+\+Msk}}~(0x\+FFFFFFUL /\texorpdfstring{$\ast$}{*}$<$$<$ \mbox{\hyperlink{group___c_m_s_i_s___c_o_r_e_gaf44d10df359dc5bf5752b0894ae3bad2}{Sys\+Tick\+\_\+\+LOAD\+\_\+\+RELOAD\+\_\+\+Pos}}\texorpdfstring{$\ast$}{*}/)
\item 
\#define \mbox{\hyperlink{group___c_m_s_i_s___c_o_r_e_ga3208104c3b019b5de35ae8c21d5c34dd}{Sys\+Tick\+\_\+\+VAL\+\_\+\+CURRENT\+\_\+\+Pos}}~0U
\item 
\#define \mbox{\hyperlink{group___c_m_s_i_s___c_o_r_e_gafc77b56d568930b49a2474debc75ab45}{Sys\+Tick\+\_\+\+VAL\+\_\+\+CURRENT\+\_\+\+Msk}}~(0x\+FFFFFFUL /\texorpdfstring{$\ast$}{*}$<$$<$ \mbox{\hyperlink{group___c_m_s_i_s___c_o_r_e_ga3208104c3b019b5de35ae8c21d5c34dd}{Sys\+Tick\+\_\+\+VAL\+\_\+\+CURRENT\+\_\+\+Pos}}\texorpdfstring{$\ast$}{*}/)
\item 
\#define \mbox{\hyperlink{group___c_m_s_i_s___c_o_r_e_ga534dbe414e7a46a6ce4c1eca1fbff409}{Sys\+Tick\+\_\+\+CALIB\+\_\+\+NOREF\+\_\+\+Pos}}~31U
\item 
\#define \mbox{\hyperlink{group___c_m_s_i_s___c_o_r_e_ga3af0d891fdd99bcc8d8912d37830edb6}{Sys\+Tick\+\_\+\+CALIB\+\_\+\+NOREF\+\_\+\+Msk}}~(1UL $<$$<$ \mbox{\hyperlink{group___c_m_s_i_s___c_o_r_e_ga534dbe414e7a46a6ce4c1eca1fbff409}{Sys\+Tick\+\_\+\+CALIB\+\_\+\+NOREF\+\_\+\+Pos}})
\item 
\#define \mbox{\hyperlink{group___c_m_s_i_s___c_o_r_e_gadd0c9cd6641b9f6a0c618e7982954860}{Sys\+Tick\+\_\+\+CALIB\+\_\+\+SKEW\+\_\+\+Pos}}~30U
\item 
\#define \mbox{\hyperlink{group___c_m_s_i_s___c_o_r_e_ga8a6a85a87334776f33d77fd147587431}{Sys\+Tick\+\_\+\+CALIB\+\_\+\+SKEW\+\_\+\+Msk}}~(1UL $<$$<$ \mbox{\hyperlink{group___c_m_s_i_s___c_o_r_e_gadd0c9cd6641b9f6a0c618e7982954860}{Sys\+Tick\+\_\+\+CALIB\+\_\+\+SKEW\+\_\+\+Pos}})
\item 
\#define \mbox{\hyperlink{group___c_m_s_i_s___c_o_r_e_gacae558f6e75a0bed5d826f606d8e695e}{Sys\+Tick\+\_\+\+CALIB\+\_\+\+TENMS\+\_\+\+Pos}}~0U
\item 
\#define \mbox{\hyperlink{group___c_m_s_i_s___c_o_r_e_gaf1e68865c5aece2ad58971225bd3e95e}{Sys\+Tick\+\_\+\+CALIB\+\_\+\+TENMS\+\_\+\+Msk}}~(0x\+FFFFFFUL /\texorpdfstring{$\ast$}{*}$<$$<$ \mbox{\hyperlink{group___c_m_s_i_s___c_o_r_e_gacae558f6e75a0bed5d826f606d8e695e}{Sys\+Tick\+\_\+\+CALIB\+\_\+\+TENMS\+\_\+\+Pos}}\texorpdfstring{$\ast$}{*}/)
\item 
\#define \mbox{\hyperlink{group___c_m_s_i_s___c_o_r_e_gafd9ed85f36233685f182cc249621e025}{ITM\+\_\+\+STIM\+\_\+\+DISABLED\+\_\+\+Pos}}~1U
\item 
\#define \mbox{\hyperlink{group___c_m_s_i_s___c_o_r_e_ga9d8f821bdad48c7b4a02f11ebf2c8852}{ITM\+\_\+\+STIM\+\_\+\+DISABLED\+\_\+\+Msk}}~(0x1\+UL $<$$<$ \mbox{\hyperlink{group___c_m_s_i_s___c_o_r_e_gafd9ed85f36233685f182cc249621e025}{ITM\+\_\+\+STIM\+\_\+\+DISABLED\+\_\+\+Pos}})
\item 
\#define \mbox{\hyperlink{group___c_m_s_i_s___c_o_r_e_gaa79f3a59d15d810d48d924c0ca4ae0b9}{ITM\+\_\+\+STIM\+\_\+\+FIFOREADY\+\_\+\+Pos}}~0U
\item 
\#define \mbox{\hyperlink{group___c_m_s_i_s___c_o_r_e_ga73dc88e3338b4ef9a81e53a1d2c5ae83}{ITM\+\_\+\+STIM\+\_\+\+FIFOREADY\+\_\+\+Msk}}~(0x1\+UL /\texorpdfstring{$\ast$}{*}$<$$<$ \mbox{\hyperlink{group___c_m_s_i_s___c_o_r_e_gaa79f3a59d15d810d48d924c0ca4ae0b9}{ITM\+\_\+\+STIM\+\_\+\+FIFOREADY\+\_\+\+Pos}}\texorpdfstring{$\ast$}{*}/)
\item 
\#define \mbox{\hyperlink{group___c_m_s_i_s___c_o_r_e_ga7abe5e590d1611599df87a1884a352e8}{ITM\+\_\+\+TPR\+\_\+\+PRIVMASK\+\_\+\+Pos}}~0U
\item 
\#define \mbox{\hyperlink{group___c_m_s_i_s___c_o_r_e_ga168e089d882df325a387aab3a802a46b}{ITM\+\_\+\+TPR\+\_\+\+PRIVMASK\+\_\+\+Msk}}~(0x\+FUL /\texorpdfstring{$\ast$}{*}$<$$<$ \mbox{\hyperlink{group___c_m_s_i_s___c_o_r_e_ga7abe5e590d1611599df87a1884a352e8}{ITM\+\_\+\+TPR\+\_\+\+PRIVMASK\+\_\+\+Pos}}\texorpdfstring{$\ast$}{*}/)
\item 
\#define \mbox{\hyperlink{group___c_m_s_i_s___c_o_r_e_ga9174ad4a36052c377cef4e6aba2ed484}{ITM\+\_\+\+TCR\+\_\+\+BUSY\+\_\+\+Pos}}~23U
\item 
\#define \mbox{\hyperlink{group___c_m_s_i_s___c_o_r_e_ga43ad7cf33de12f2ef3a412d4f354c60f}{ITM\+\_\+\+TCR\+\_\+\+BUSY\+\_\+\+Msk}}~(1UL $<$$<$ \mbox{\hyperlink{group___c_m_s_i_s___c_o_r_e_ga9174ad4a36052c377cef4e6aba2ed484}{ITM\+\_\+\+TCR\+\_\+\+BUSY\+\_\+\+Pos}})
\item 
\#define \mbox{\hyperlink{group___c_m_s_i_s___c_o_r_e_ga113bf41ed31584360ad7d865e5e0ace7}{ITM\+\_\+\+TCR\+\_\+\+TRACEBUSID\+\_\+\+Pos}}~16U
\item 
\#define \mbox{\hyperlink{group___c_m_s_i_s___c_o_r_e_gac014c7345304ed245b642eb9d6e9a302}{ITM\+\_\+\+TCR\+\_\+\+TRACEBUSID\+\_\+\+Msk}}~(0x7\+FUL $<$$<$ \mbox{\hyperlink{group___c_m_s_i_s___c_o_r_e_ga113bf41ed31584360ad7d865e5e0ace7}{ITM\+\_\+\+TCR\+\_\+\+TRACEBUSID\+\_\+\+Pos}})
\item 
\#define \mbox{\hyperlink{group___c_m_s_i_s___c_o_r_e_ga96c7c7cbc0d98426c408090b41f583f1}{ITM\+\_\+\+TCR\+\_\+\+GTSFREQ\+\_\+\+Pos}}~10U
\item 
\#define \mbox{\hyperlink{group___c_m_s_i_s___c_o_r_e_gade862cf009827f7f6748fc44c541b067}{ITM\+\_\+\+TCR\+\_\+\+GTSFREQ\+\_\+\+Msk}}~(3UL $<$$<$ \mbox{\hyperlink{group___c_m_s_i_s___c_o_r_e_ga96c7c7cbc0d98426c408090b41f583f1}{ITM\+\_\+\+TCR\+\_\+\+GTSFREQ\+\_\+\+Pos}})
\item 
\#define \mbox{\hyperlink{group___c_m_s_i_s___c_o_r_e_gaa39e93e22d56e5e9edaf866b1171ac4f}{ITM\+\_\+\+TCR\+\_\+\+TSPRESCALE\+\_\+\+Pos}}~8U
\item 
\#define \mbox{\hyperlink{group___c_m_s_i_s___c_o_r_e_ga3e8651ecde89295bcc6e248a1b7393d6}{ITM\+\_\+\+TCR\+\_\+\+TSPRESCALE\+\_\+\+Msk}}~(3UL $<$$<$ \mbox{\hyperlink{group___c_m_s_i_s___c_o_r_e_gaa39e93e22d56e5e9edaf866b1171ac4f}{ITM\+\_\+\+TCR\+\_\+\+TSPRESCALE\+\_\+\+Pos}})
\item 
\#define \mbox{\hyperlink{group___c_m_s_i_s___c_o_r_e_gad74ca6140644b572eadbf21e870d24b9}{ITM\+\_\+\+TCR\+\_\+\+STALLENA\+\_\+\+Pos}}~5U
\item 
\#define \mbox{\hyperlink{group___c_m_s_i_s___c_o_r_e_ga724f0560593042670b49e2f9a6483b6f}{ITM\+\_\+\+TCR\+\_\+\+STALLENA\+\_\+\+Msk}}~(1UL $<$$<$ \mbox{\hyperlink{group___c_m_s_i_s___c_o_r_e_gad74ca6140644b572eadbf21e870d24b9}{ITM\+\_\+\+TCR\+\_\+\+STALLENA\+\_\+\+Pos}})
\item 
\#define \mbox{\hyperlink{group___c_m_s_i_s___c_o_r_e_ga7a380f0c8078f6560051406583ecd6a5}{ITM\+\_\+\+TCR\+\_\+\+SWOENA\+\_\+\+Pos}}~4U
\item 
\#define \mbox{\hyperlink{group___c_m_s_i_s___c_o_r_e_ga97476cb65bab16a328b35f81fd02010a}{ITM\+\_\+\+TCR\+\_\+\+SWOENA\+\_\+\+Msk}}~(1UL $<$$<$ \mbox{\hyperlink{group___c_m_s_i_s___c_o_r_e_ga7a380f0c8078f6560051406583ecd6a5}{ITM\+\_\+\+TCR\+\_\+\+SWOENA\+\_\+\+Pos}})
\item 
\#define \mbox{\hyperlink{group___c_m_s_i_s___c_o_r_e_ga30e83ebb33aa766070fe3d1f27ae820e}{ITM\+\_\+\+TCR\+\_\+\+DWTENA\+\_\+\+Pos}}~3U
\item 
\#define \mbox{\hyperlink{group___c_m_s_i_s___c_o_r_e_ga98ea1c596d43d3633a202f9ee746cf70}{ITM\+\_\+\+TCR\+\_\+\+DWTENA\+\_\+\+Msk}}~(1UL $<$$<$ \mbox{\hyperlink{group___c_m_s_i_s___c_o_r_e_ga30e83ebb33aa766070fe3d1f27ae820e}{ITM\+\_\+\+TCR\+\_\+\+DWTENA\+\_\+\+Pos}})
\item 
\#define \mbox{\hyperlink{group___c_m_s_i_s___c_o_r_e_gaa93a1147a39fc63980d299231252a30e}{ITM\+\_\+\+TCR\+\_\+\+SYNCENA\+\_\+\+Pos}}~2U
\item 
\#define \mbox{\hyperlink{group___c_m_s_i_s___c_o_r_e_gac89b74a78701c25b442105d7fe2bbefb}{ITM\+\_\+\+TCR\+\_\+\+SYNCENA\+\_\+\+Msk}}~(1UL $<$$<$ \mbox{\hyperlink{group___c_m_s_i_s___c_o_r_e_gaa93a1147a39fc63980d299231252a30e}{ITM\+\_\+\+TCR\+\_\+\+SYNCENA\+\_\+\+Pos}})
\item 
\#define \mbox{\hyperlink{group___c_m_s_i_s___c_o_r_e_ga5aa381845f810114ab519b90753922a1}{ITM\+\_\+\+TCR\+\_\+\+TSENA\+\_\+\+Pos}}~1U
\item 
\#define \mbox{\hyperlink{group___c_m_s_i_s___c_o_r_e_ga436b2e8fa24328f48f2da31c00fc9e65}{ITM\+\_\+\+TCR\+\_\+\+TSENA\+\_\+\+Msk}}~(1UL $<$$<$ \mbox{\hyperlink{group___c_m_s_i_s___c_o_r_e_ga5aa381845f810114ab519b90753922a1}{ITM\+\_\+\+TCR\+\_\+\+TSENA\+\_\+\+Pos}})
\item 
\#define \mbox{\hyperlink{group___c_m_s_i_s___c_o_r_e_ga3286b86004bce7ffe17ee269f87f8d9d}{ITM\+\_\+\+TCR\+\_\+\+ITMENA\+\_\+\+Pos}}~0U
\item 
\#define \mbox{\hyperlink{group___c_m_s_i_s___c_o_r_e_ga7dd53e3bff24ac09d94e61cb595cb2d9}{ITM\+\_\+\+TCR\+\_\+\+ITMENA\+\_\+\+Msk}}~(1UL /\texorpdfstring{$\ast$}{*}$<$$<$ \mbox{\hyperlink{group___c_m_s_i_s___c_o_r_e_ga3286b86004bce7ffe17ee269f87f8d9d}{ITM\+\_\+\+TCR\+\_\+\+ITMENA\+\_\+\+Pos}}\texorpdfstring{$\ast$}{*}/)
\item 
\#define \mbox{\hyperlink{group___c_m_s_i_s___c_o_r_e_gabfae3e570edc8759597311ed6dfb478e}{ITM\+\_\+\+LSR\+\_\+\+Byte\+Acc\+\_\+\+Pos}}~2U
\item 
\#define \mbox{\hyperlink{group___c_m_s_i_s___c_o_r_e_ga91f492b2891bb8b7eac5b58de7b220f4}{ITM\+\_\+\+LSR\+\_\+\+Byte\+Acc\+\_\+\+Msk}}~(1UL $<$$<$ \mbox{\hyperlink{group___c_m_s_i_s___c_o_r_e_gabfae3e570edc8759597311ed6dfb478e}{ITM\+\_\+\+LSR\+\_\+\+Byte\+Acc\+\_\+\+Pos}})
\item 
\#define \mbox{\hyperlink{group___c_m_s_i_s___c_o_r_e_ga144a49e12b83ad9809fdd2769094fdc0}{ITM\+\_\+\+LSR\+\_\+\+Access\+\_\+\+Pos}}~1U
\item 
\#define \mbox{\hyperlink{group___c_m_s_i_s___c_o_r_e_gac8ae69f11c0311da226c0c8ec40b3d37}{ITM\+\_\+\+LSR\+\_\+\+Access\+\_\+\+Msk}}~(1UL $<$$<$ \mbox{\hyperlink{group___c_m_s_i_s___c_o_r_e_ga144a49e12b83ad9809fdd2769094fdc0}{ITM\+\_\+\+LSR\+\_\+\+Access\+\_\+\+Pos}})
\item 
\#define \mbox{\hyperlink{group___c_m_s_i_s___c_o_r_e_gaf5740689cf14564d3f3fd91299b6c88d}{ITM\+\_\+\+LSR\+\_\+\+Present\+\_\+\+Pos}}~0U
\item 
\#define \mbox{\hyperlink{group___c_m_s_i_s___c_o_r_e_gaa5bc2a7f5f1d69ff819531f5508bb017}{ITM\+\_\+\+LSR\+\_\+\+Present\+\_\+\+Msk}}~(1UL /\texorpdfstring{$\ast$}{*}$<$$<$ \mbox{\hyperlink{group___c_m_s_i_s___c_o_r_e_gaf5740689cf14564d3f3fd91299b6c88d}{ITM\+\_\+\+LSR\+\_\+\+Present\+\_\+\+Pos}}\texorpdfstring{$\ast$}{*}/)
\item 
\#define \mbox{\hyperlink{group___c_m_s_i_s___c_o_r_e_gaac44b9b7d5391a7ffef129b7f6c84cd7}{DWT\+\_\+\+CTRL\+\_\+\+NUMCOMP\+\_\+\+Pos}}~28U
\item 
\#define \mbox{\hyperlink{group___c_m_s_i_s___c_o_r_e_gaa3d37d68c2ba73f2026265584c2815e7}{DWT\+\_\+\+CTRL\+\_\+\+NUMCOMP\+\_\+\+Msk}}~(0x\+FUL $<$$<$ \mbox{\hyperlink{group___c_m_s_i_s___c_o_r_e_gaac44b9b7d5391a7ffef129b7f6c84cd7}{DWT\+\_\+\+CTRL\+\_\+\+NUMCOMP\+\_\+\+Pos}})
\item 
\#define \mbox{\hyperlink{group___c_m_s_i_s___c_o_r_e_gaa82840323a2628e7f4a2b09b74fa73fd}{DWT\+\_\+\+CTRL\+\_\+\+NOTRCPKT\+\_\+\+Pos}}~27U
\item 
\#define \mbox{\hyperlink{group___c_m_s_i_s___c_o_r_e_ga04d8bb0a065ca38e2e5f13a97e1f7073}{DWT\+\_\+\+CTRL\+\_\+\+NOTRCPKT\+\_\+\+Msk}}~(0x1\+UL $<$$<$ \mbox{\hyperlink{group___c_m_s_i_s___c_o_r_e_gaa82840323a2628e7f4a2b09b74fa73fd}{DWT\+\_\+\+CTRL\+\_\+\+NOTRCPKT\+\_\+\+Pos}})
\item 
\#define \mbox{\hyperlink{group___c_m_s_i_s___c_o_r_e_gad997b9026715d5609b5a3b144eca42d0}{DWT\+\_\+\+CTRL\+\_\+\+NOEXTTRIG\+\_\+\+Pos}}~26U
\item 
\#define \mbox{\hyperlink{group___c_m_s_i_s___c_o_r_e_gacc7d15edf7a27147c422099ab475953e}{DWT\+\_\+\+CTRL\+\_\+\+NOEXTTRIG\+\_\+\+Msk}}~(0x1\+UL $<$$<$ \mbox{\hyperlink{group___c_m_s_i_s___c_o_r_e_gad997b9026715d5609b5a3b144eca42d0}{DWT\+\_\+\+CTRL\+\_\+\+NOEXTTRIG\+\_\+\+Pos}})
\item 
\#define \mbox{\hyperlink{group___c_m_s_i_s___c_o_r_e_ga337f6167d960f57f12aa382ffecce522}{DWT\+\_\+\+CTRL\+\_\+\+NOCYCCNT\+\_\+\+Pos}}~25U
\item 
\#define \mbox{\hyperlink{group___c_m_s_i_s___c_o_r_e_gaf40c8d7a4fd978034c137e90f714c143}{DWT\+\_\+\+CTRL\+\_\+\+NOCYCCNT\+\_\+\+Msk}}~(0x1\+UL $<$$<$ \mbox{\hyperlink{group___c_m_s_i_s___c_o_r_e_ga337f6167d960f57f12aa382ffecce522}{DWT\+\_\+\+CTRL\+\_\+\+NOCYCCNT\+\_\+\+Pos}})
\item 
\#define \mbox{\hyperlink{group___c_m_s_i_s___c_o_r_e_gad52a0e5be84363ab166cc17beca0d048}{DWT\+\_\+\+CTRL\+\_\+\+NOPRFCNT\+\_\+\+Pos}}~24U
\item 
\#define \mbox{\hyperlink{group___c_m_s_i_s___c_o_r_e_gafd8448d7db4bc51f27f202e6e1f27823}{DWT\+\_\+\+CTRL\+\_\+\+NOPRFCNT\+\_\+\+Msk}}~(0x1\+UL $<$$<$ \mbox{\hyperlink{group___c_m_s_i_s___c_o_r_e_gad52a0e5be84363ab166cc17beca0d048}{DWT\+\_\+\+CTRL\+\_\+\+NOPRFCNT\+\_\+\+Pos}})
\item 
\#define \mbox{\hyperlink{group___c_m_s_i_s___c_o_r_e_ga555f3a6b0510368a2bba4f0e06e559c3}{DWT\+\_\+\+CTRL\+\_\+\+CYCDISS\+\_\+\+Pos}}~23U
\item 
\#define \mbox{\hyperlink{group___c_m_s_i_s___c_o_r_e_ga688a3b9ecd2a044f2da3280367476271}{DWT\+\_\+\+CTRL\+\_\+\+CYCDISS\+\_\+\+Msk}}~(0x1\+UL $<$$<$ \mbox{\hyperlink{group___c_m_s_i_s___c_o_r_e_ga555f3a6b0510368a2bba4f0e06e559c3}{DWT\+\_\+\+CTRL\+\_\+\+CYCDISS\+\_\+\+Pos}})
\item 
\#define \mbox{\hyperlink{group___c_m_s_i_s___c_o_r_e_ga0cb0640aaeb18a626d7823570d5c3cb6}{DWT\+\_\+\+CTRL\+\_\+\+CYCEVTENA\+\_\+\+Pos}}~22U
\item 
\#define \mbox{\hyperlink{group___c_m_s_i_s___c_o_r_e_ga40554bd81460e39abf08810f45fac1a2}{DWT\+\_\+\+CTRL\+\_\+\+CYCEVTENA\+\_\+\+Msk}}~(0x1\+UL $<$$<$ \mbox{\hyperlink{group___c_m_s_i_s___c_o_r_e_ga0cb0640aaeb18a626d7823570d5c3cb6}{DWT\+\_\+\+CTRL\+\_\+\+CYCEVTENA\+\_\+\+Pos}})
\item 
\#define \mbox{\hyperlink{group___c_m_s_i_s___c_o_r_e_ga5602b0707f446ce78d88ff2a3a82bfff}{DWT\+\_\+\+CTRL\+\_\+\+FOLDEVTENA\+\_\+\+Pos}}~21U
\item 
\#define \mbox{\hyperlink{group___c_m_s_i_s___c_o_r_e_ga717e679d775562ae09185a3776b1582f}{DWT\+\_\+\+CTRL\+\_\+\+FOLDEVTENA\+\_\+\+Msk}}~(0x1\+UL $<$$<$ \mbox{\hyperlink{group___c_m_s_i_s___c_o_r_e_ga5602b0707f446ce78d88ff2a3a82bfff}{DWT\+\_\+\+CTRL\+\_\+\+FOLDEVTENA\+\_\+\+Pos}})
\item 
\#define \mbox{\hyperlink{group___c_m_s_i_s___c_o_r_e_gaea5d1ee72188dc1d57b54c60a9f5233e}{DWT\+\_\+\+CTRL\+\_\+\+LSUEVTENA\+\_\+\+Pos}}~20U
\item 
\#define \mbox{\hyperlink{group___c_m_s_i_s___c_o_r_e_gac47427f455fbc29d4b6f8a479169f2b2}{DWT\+\_\+\+CTRL\+\_\+\+LSUEVTENA\+\_\+\+Msk}}~(0x1\+UL $<$$<$ \mbox{\hyperlink{group___c_m_s_i_s___c_o_r_e_gaea5d1ee72188dc1d57b54c60a9f5233e}{DWT\+\_\+\+CTRL\+\_\+\+LSUEVTENA\+\_\+\+Pos}})
\item 
\#define \mbox{\hyperlink{group___c_m_s_i_s___c_o_r_e_ga9c6d62d121164013a8e3ee372f17f3e5}{DWT\+\_\+\+CTRL\+\_\+\+SLEEPEVTENA\+\_\+\+Pos}}~19U
\item 
\#define \mbox{\hyperlink{group___c_m_s_i_s___c_o_r_e_ga2f431b3734fb840daf5b361034856da9}{DWT\+\_\+\+CTRL\+\_\+\+SLEEPEVTENA\+\_\+\+Msk}}~(0x1\+UL $<$$<$ \mbox{\hyperlink{group___c_m_s_i_s___c_o_r_e_ga9c6d62d121164013a8e3ee372f17f3e5}{DWT\+\_\+\+CTRL\+\_\+\+SLEEPEVTENA\+\_\+\+Pos}})
\item 
\#define \mbox{\hyperlink{group___c_m_s_i_s___c_o_r_e_gaf4e73f548ae3e945ef8b1d9ff1281544}{DWT\+\_\+\+CTRL\+\_\+\+EXCEVTENA\+\_\+\+Pos}}~18U
\item 
\#define \mbox{\hyperlink{group___c_m_s_i_s___c_o_r_e_gab7ee0def33423b5859ca4030dff63b58}{DWT\+\_\+\+CTRL\+\_\+\+EXCEVTENA\+\_\+\+Msk}}~(0x1\+UL $<$$<$ \mbox{\hyperlink{group___c_m_s_i_s___c_o_r_e_gaf4e73f548ae3e945ef8b1d9ff1281544}{DWT\+\_\+\+CTRL\+\_\+\+EXCEVTENA\+\_\+\+Pos}})
\item 
\#define \mbox{\hyperlink{group___c_m_s_i_s___c_o_r_e_ga9fff0b71fb0be1499f5180c6bce1fc8f}{DWT\+\_\+\+CTRL\+\_\+\+CPIEVTENA\+\_\+\+Pos}}~17U
\item 
\#define \mbox{\hyperlink{group___c_m_s_i_s___c_o_r_e_ga189089c30aade60b983df17ad2412f6f}{DWT\+\_\+\+CTRL\+\_\+\+CPIEVTENA\+\_\+\+Msk}}~(0x1\+UL $<$$<$ \mbox{\hyperlink{group___c_m_s_i_s___c_o_r_e_ga9fff0b71fb0be1499f5180c6bce1fc8f}{DWT\+\_\+\+CTRL\+\_\+\+CPIEVTENA\+\_\+\+Pos}})
\item 
\#define \mbox{\hyperlink{group___c_m_s_i_s___c_o_r_e_ga05f13b547a9a1e63e003ee0bc6446d0d}{DWT\+\_\+\+CTRL\+\_\+\+EXCTRCENA\+\_\+\+Pos}}~16U
\item 
\#define \mbox{\hyperlink{group___c_m_s_i_s___c_o_r_e_gaf4fbb509ab3cbb768f16484c660a24c3}{DWT\+\_\+\+CTRL\+\_\+\+EXCTRCENA\+\_\+\+Msk}}~(0x1\+UL $<$$<$ \mbox{\hyperlink{group___c_m_s_i_s___c_o_r_e_ga05f13b547a9a1e63e003ee0bc6446d0d}{DWT\+\_\+\+CTRL\+\_\+\+EXCTRCENA\+\_\+\+Pos}})
\item 
\#define \mbox{\hyperlink{group___c_m_s_i_s___c_o_r_e_ga1e14afc7790fcb424fcf619e192554c9}{DWT\+\_\+\+CTRL\+\_\+\+PCSAMPLENA\+\_\+\+Pos}}~12U
\item 
\#define \mbox{\hyperlink{group___c_m_s_i_s___c_o_r_e_gafdcf1c86f43fbeaf2780ce797c9ef3d6}{DWT\+\_\+\+CTRL\+\_\+\+PCSAMPLENA\+\_\+\+Msk}}~(0x1\+UL $<$$<$ \mbox{\hyperlink{group___c_m_s_i_s___c_o_r_e_ga1e14afc7790fcb424fcf619e192554c9}{DWT\+\_\+\+CTRL\+\_\+\+PCSAMPLENA\+\_\+\+Pos}})
\item 
\#define \mbox{\hyperlink{group___c_m_s_i_s___c_o_r_e_ga678ef08786edcbef964479217efb9284}{DWT\+\_\+\+CTRL\+\_\+\+SYNCTAP\+\_\+\+Pos}}~10U
\item 
\#define \mbox{\hyperlink{group___c_m_s_i_s___c_o_r_e_gaf1e6c3729d56ecadeb6eeff4d225968c}{DWT\+\_\+\+CTRL\+\_\+\+SYNCTAP\+\_\+\+Msk}}~(0x3\+UL $<$$<$ \mbox{\hyperlink{group___c_m_s_i_s___c_o_r_e_ga678ef08786edcbef964479217efb9284}{DWT\+\_\+\+CTRL\+\_\+\+SYNCTAP\+\_\+\+Pos}})
\item 
\#define \mbox{\hyperlink{group___c_m_s_i_s___c_o_r_e_gaf70b80936c7db60bf84fb6dadb8a3559}{DWT\+\_\+\+CTRL\+\_\+\+CYCTAP\+\_\+\+Pos}}~9U
\item 
\#define \mbox{\hyperlink{group___c_m_s_i_s___c_o_r_e_ga6c12e2868b8989a69445646698b8c331}{DWT\+\_\+\+CTRL\+\_\+\+CYCTAP\+\_\+\+Msk}}~(0x1\+UL $<$$<$ \mbox{\hyperlink{group___c_m_s_i_s___c_o_r_e_gaf70b80936c7db60bf84fb6dadb8a3559}{DWT\+\_\+\+CTRL\+\_\+\+CYCTAP\+\_\+\+Pos}})
\item 
\#define \mbox{\hyperlink{group___c_m_s_i_s___c_o_r_e_ga2868c0b28eb13be930afb819f55f6f25}{DWT\+\_\+\+CTRL\+\_\+\+POSTINIT\+\_\+\+Pos}}~5U
\item 
\#define \mbox{\hyperlink{group___c_m_s_i_s___c_o_r_e_gab8cbbee1e1d94d09f9a1f86379a08ee8}{DWT\+\_\+\+CTRL\+\_\+\+POSTINIT\+\_\+\+Msk}}~(0x\+FUL $<$$<$ \mbox{\hyperlink{group___c_m_s_i_s___c_o_r_e_ga2868c0b28eb13be930afb819f55f6f25}{DWT\+\_\+\+CTRL\+\_\+\+POSTINIT\+\_\+\+Pos}})
\item 
\#define \mbox{\hyperlink{group___c_m_s_i_s___c_o_r_e_ga129bc152febfddd67a0c20c6814cba69}{DWT\+\_\+\+CTRL\+\_\+\+POSTPRESET\+\_\+\+Pos}}~1U
\item 
\#define \mbox{\hyperlink{group___c_m_s_i_s___c_o_r_e_ga11d9e1e2a758fdd2657aa68ce61b9c9d}{DWT\+\_\+\+CTRL\+\_\+\+POSTPRESET\+\_\+\+Msk}}~(0x\+FUL $<$$<$ \mbox{\hyperlink{group___c_m_s_i_s___c_o_r_e_ga129bc152febfddd67a0c20c6814cba69}{DWT\+\_\+\+CTRL\+\_\+\+POSTPRESET\+\_\+\+Pos}})
\item 
\#define \mbox{\hyperlink{group___c_m_s_i_s___c_o_r_e_gaa4509f5f8514a7200be61691f0e01f10}{DWT\+\_\+\+CTRL\+\_\+\+CYCCNTENA\+\_\+\+Pos}}~0U
\item 
\#define \mbox{\hyperlink{group___c_m_s_i_s___c_o_r_e_ga4a9d209dc2a81ea6bfa0ea21331769d3}{DWT\+\_\+\+CTRL\+\_\+\+CYCCNTENA\+\_\+\+Msk}}~(0x1\+UL /\texorpdfstring{$\ast$}{*}$<$$<$ \mbox{\hyperlink{group___c_m_s_i_s___c_o_r_e_gaa4509f5f8514a7200be61691f0e01f10}{DWT\+\_\+\+CTRL\+\_\+\+CYCCNTENA\+\_\+\+Pos}}\texorpdfstring{$\ast$}{*}/)
\item 
\#define \mbox{\hyperlink{group___c_m_s_i_s___c_o_r_e_ga80e9ad8f6a9e2344af8a3cf989bebe3d}{DWT\+\_\+\+CPICNT\+\_\+\+CPICNT\+\_\+\+Pos}}~0U
\item 
\#define \mbox{\hyperlink{group___c_m_s_i_s___c_o_r_e_ga76f39e7bca3fa86a4dbf7b8f6adb7217}{DWT\+\_\+\+CPICNT\+\_\+\+CPICNT\+\_\+\+Msk}}~(0x\+FFUL /\texorpdfstring{$\ast$}{*}$<$$<$ \mbox{\hyperlink{group___c_m_s_i_s___c_o_r_e_ga80e9ad8f6a9e2344af8a3cf989bebe3d}{DWT\+\_\+\+CPICNT\+\_\+\+CPICNT\+\_\+\+Pos}}\texorpdfstring{$\ast$}{*}/)
\item 
\#define \mbox{\hyperlink{group___c_m_s_i_s___c_o_r_e_ga031c693654030d4cba398b45d2925b1d}{DWT\+\_\+\+EXCCNT\+\_\+\+EXCCNT\+\_\+\+Pos}}~0U
\item 
\#define \mbox{\hyperlink{group___c_m_s_i_s___c_o_r_e_ga057fa604a107b58a198bbbadb47e69c9}{DWT\+\_\+\+EXCCNT\+\_\+\+EXCCNT\+\_\+\+Msk}}~(0x\+FFUL /\texorpdfstring{$\ast$}{*}$<$$<$ \mbox{\hyperlink{group___c_m_s_i_s___c_o_r_e_ga031c693654030d4cba398b45d2925b1d}{DWT\+\_\+\+EXCCNT\+\_\+\+EXCCNT\+\_\+\+Pos}}\texorpdfstring{$\ast$}{*}/)
\item 
\#define \mbox{\hyperlink{group___c_m_s_i_s___c_o_r_e_ga0371a84a7996dc5852c56afb2676ba1c}{DWT\+\_\+\+SLEEPCNT\+\_\+\+SLEEPCNT\+\_\+\+Pos}}~0U
\item 
\#define \mbox{\hyperlink{group___c_m_s_i_s___c_o_r_e_ga1e340751d71413fef400a0a1d76cc828}{DWT\+\_\+\+SLEEPCNT\+\_\+\+SLEEPCNT\+\_\+\+Msk}}~(0x\+FFUL /\texorpdfstring{$\ast$}{*}$<$$<$ \mbox{\hyperlink{group___c_m_s_i_s___c_o_r_e_ga0371a84a7996dc5852c56afb2676ba1c}{DWT\+\_\+\+SLEEPCNT\+\_\+\+SLEEPCNT\+\_\+\+Pos}}\texorpdfstring{$\ast$}{*}/)
\item 
\#define \mbox{\hyperlink{group___c_m_s_i_s___c_o_r_e_gab9394c7911b0b4312a096dad91d53a3d}{DWT\+\_\+\+LSUCNT\+\_\+\+LSUCNT\+\_\+\+Pos}}~0U
\item 
\#define \mbox{\hyperlink{group___c_m_s_i_s___c_o_r_e_ga2186d7fc9317e20bad61336ee2925615}{DWT\+\_\+\+LSUCNT\+\_\+\+LSUCNT\+\_\+\+Msk}}~(0x\+FFUL /\texorpdfstring{$\ast$}{*}$<$$<$ \mbox{\hyperlink{group___c_m_s_i_s___c_o_r_e_gab9394c7911b0b4312a096dad91d53a3d}{DWT\+\_\+\+LSUCNT\+\_\+\+LSUCNT\+\_\+\+Pos}}\texorpdfstring{$\ast$}{*}/)
\item 
\#define \mbox{\hyperlink{group___c_m_s_i_s___c_o_r_e_ga7f8af5ac12d178ba31a516f6ed141455}{DWT\+\_\+\+FOLDCNT\+\_\+\+FOLDCNT\+\_\+\+Pos}}~0U
\item 
\#define \mbox{\hyperlink{group___c_m_s_i_s___c_o_r_e_ga9cb73d0342d38b14e41027d3c5c02647}{DWT\+\_\+\+FOLDCNT\+\_\+\+FOLDCNT\+\_\+\+Msk}}~(0x\+FFUL /\texorpdfstring{$\ast$}{*}$<$$<$ \mbox{\hyperlink{group___c_m_s_i_s___c_o_r_e_ga7f8af5ac12d178ba31a516f6ed141455}{DWT\+\_\+\+FOLDCNT\+\_\+\+FOLDCNT\+\_\+\+Pos}}\texorpdfstring{$\ast$}{*}/)
\item 
\#define \mbox{\hyperlink{group___c_m_s_i_s___c_o_r_e_gae5dfe4049c2291e413f8713d7bd2bb1b}{DWT\+\_\+\+FUNCTION\+\_\+\+ID\+\_\+\+Pos}}~27U
\item 
\#define \mbox{\hyperlink{group___c_m_s_i_s___c_o_r_e_ga6bc2e15fcc300f511f64dad561c97582}{DWT\+\_\+\+FUNCTION\+\_\+\+ID\+\_\+\+Msk}}~(0x1\+FUL $<$$<$ \mbox{\hyperlink{group___c_m_s_i_s___c_o_r_e_gae5dfe4049c2291e413f8713d7bd2bb1b}{DWT\+\_\+\+FUNCTION\+\_\+\+ID\+\_\+\+Pos}})
\item 
\#define \mbox{\hyperlink{group___c_m_s_i_s___c_o_r_e_ga22c5787493f74a6bacf6ffb103a190ba}{DWT\+\_\+\+FUNCTION\+\_\+\+MATCHED\+\_\+\+Pos}}~24U
\item 
\#define \mbox{\hyperlink{group___c_m_s_i_s___c_o_r_e_gac8b1a655947490280709037808eec8ac}{DWT\+\_\+\+FUNCTION\+\_\+\+MATCHED\+\_\+\+Msk}}~(0x1\+UL $<$$<$ \mbox{\hyperlink{group___c_m_s_i_s___c_o_r_e_ga22c5787493f74a6bacf6ffb103a190ba}{DWT\+\_\+\+FUNCTION\+\_\+\+MATCHED\+\_\+\+Pos}})
\item 
\#define \mbox{\hyperlink{group___c_m_s_i_s___c_o_r_e_ga0517a186d4d448aa6416440f40fe7a4d}{DWT\+\_\+\+FUNCTION\+\_\+\+DATAVSIZE\+\_\+\+Pos}}~10U
\item 
\#define \mbox{\hyperlink{group___c_m_s_i_s___c_o_r_e_gaab42cbc1e6084c44d5de70971613ea76}{DWT\+\_\+\+FUNCTION\+\_\+\+DATAVSIZE\+\_\+\+Msk}}~(0x3\+UL $<$$<$ \mbox{\hyperlink{group___c_m_s_i_s___c_o_r_e_ga0517a186d4d448aa6416440f40fe7a4d}{DWT\+\_\+\+FUNCTION\+\_\+\+DATAVSIZE\+\_\+\+Pos}})
\item 
\#define \mbox{\hyperlink{group___c_m_s_i_s___c_o_r_e_ga00893dd43b824ca5be80e0235a237485}{DWT\+\_\+\+FUNCTION\+\_\+\+ACTION\+\_\+\+Pos}}~4U
\item 
\#define \mbox{\hyperlink{group___c_m_s_i_s___c_o_r_e_ga4d104412bbadbbfbde1c6da0f9b0fc3e}{DWT\+\_\+\+FUNCTION\+\_\+\+ACTION\+\_\+\+Msk}}~(0x1\+UL $<$$<$ \mbox{\hyperlink{group___c_m_s_i_s___c_o_r_e_ga00893dd43b824ca5be80e0235a237485}{DWT\+\_\+\+FUNCTION\+\_\+\+ACTION\+\_\+\+Pos}})
\item 
\#define \mbox{\hyperlink{group___c_m_s_i_s___c_o_r_e_ga4108994a9eb6b2cd8d8289b1b7824fe5}{DWT\+\_\+\+FUNCTION\+\_\+\+MATCH\+\_\+\+Pos}}~0U
\item 
\#define \mbox{\hyperlink{group___c_m_s_i_s___c_o_r_e_gac2fb3e387e405a4b33fc5ba0bea5b21c}{DWT\+\_\+\+FUNCTION\+\_\+\+MATCH\+\_\+\+Msk}}~(0x\+FUL /\texorpdfstring{$\ast$}{*}$<$$<$ \mbox{\hyperlink{group___c_m_s_i_s___c_o_r_e_ga4108994a9eb6b2cd8d8289b1b7824fe5}{DWT\+\_\+\+FUNCTION\+\_\+\+MATCH\+\_\+\+Pos}}\texorpdfstring{$\ast$}{*}/)
\item 
\#define \mbox{\hyperlink{group___c_m_s_i_s___c_o_r_e_ga0f302797b94bb2da24052082ab630858}{TPI\+\_\+\+SPPR\+\_\+\+TXMODE\+\_\+\+Pos}}~0U
\item 
\#define \mbox{\hyperlink{group___c_m_s_i_s___c_o_r_e_gaca085c8a954393d70dbd7240bb02cc1f}{TPI\+\_\+\+SPPR\+\_\+\+TXMODE\+\_\+\+Msk}}~(0x3\+UL /\texorpdfstring{$\ast$}{*}$<$$<$ \mbox{\hyperlink{group___c_m_s_i_s___c_o_r_e_ga0f302797b94bb2da24052082ab630858}{TPI\+\_\+\+SPPR\+\_\+\+TXMODE\+\_\+\+Pos}}\texorpdfstring{$\ast$}{*}/)
\item 
\#define \mbox{\hyperlink{group___c_m_s_i_s___c_o_r_e_ga9537b8a660cc8803f57cbbee320b2fc8}{TPI\+\_\+\+FFSR\+\_\+\+Ft\+Non\+Stop\+\_\+\+Pos}}~3U
\item 
\#define \mbox{\hyperlink{group___c_m_s_i_s___c_o_r_e_gaaa313f980974a8cfc7dac68c4d805ab1}{TPI\+\_\+\+FFSR\+\_\+\+Ft\+Non\+Stop\+\_\+\+Msk}}~(0x1\+UL $<$$<$ \mbox{\hyperlink{group___c_m_s_i_s___c_o_r_e_ga9537b8a660cc8803f57cbbee320b2fc8}{TPI\+\_\+\+FFSR\+\_\+\+Ft\+Non\+Stop\+\_\+\+Pos}})
\item 
\#define \mbox{\hyperlink{group___c_m_s_i_s___c_o_r_e_gad30fde0c058da2ffb2b0a213be7a1b5c}{TPI\+\_\+\+FFSR\+\_\+\+TCPresent\+\_\+\+Pos}}~2U
\item 
\#define \mbox{\hyperlink{group___c_m_s_i_s___c_o_r_e_ga0d6bfd263ff2fdec72d6ec9415fb1135}{TPI\+\_\+\+FFSR\+\_\+\+TCPresent\+\_\+\+Msk}}~(0x1\+UL $<$$<$ \mbox{\hyperlink{group___c_m_s_i_s___c_o_r_e_gad30fde0c058da2ffb2b0a213be7a1b5c}{TPI\+\_\+\+FFSR\+\_\+\+TCPresent\+\_\+\+Pos}})
\item 
\#define \mbox{\hyperlink{group___c_m_s_i_s___c_o_r_e_gaedf31fd453a878021b542b644e2869d2}{TPI\+\_\+\+FFSR\+\_\+\+Ft\+Stopped\+\_\+\+Pos}}~1U
\item 
\#define \mbox{\hyperlink{group___c_m_s_i_s___c_o_r_e_ga1ab6c3abe1cf6311ee07e7c479ce5f78}{TPI\+\_\+\+FFSR\+\_\+\+Ft\+Stopped\+\_\+\+Msk}}~(0x1\+UL $<$$<$ \mbox{\hyperlink{group___c_m_s_i_s___c_o_r_e_gaedf31fd453a878021b542b644e2869d2}{TPI\+\_\+\+FFSR\+\_\+\+Ft\+Stopped\+\_\+\+Pos}})
\item 
\#define \mbox{\hyperlink{group___c_m_s_i_s___c_o_r_e_ga542ca74a081588273e6d5275ba5da6bf}{TPI\+\_\+\+FFSR\+\_\+\+Fl\+In\+Prog\+\_\+\+Pos}}~0U
\item 
\#define \mbox{\hyperlink{group___c_m_s_i_s___c_o_r_e_ga63dfb09259893958962914fc3a9e3824}{TPI\+\_\+\+FFSR\+\_\+\+Fl\+In\+Prog\+\_\+\+Msk}}~(0x1\+UL /\texorpdfstring{$\ast$}{*}$<$$<$ \mbox{\hyperlink{group___c_m_s_i_s___c_o_r_e_ga542ca74a081588273e6d5275ba5da6bf}{TPI\+\_\+\+FFSR\+\_\+\+Fl\+In\+Prog\+\_\+\+Pos}}\texorpdfstring{$\ast$}{*}/)
\item 
\#define \mbox{\hyperlink{group___c_m_s_i_s___c_o_r_e_gaa7ea11ba6ea75b541cd82e185c725b5b}{TPI\+\_\+\+FFCR\+\_\+\+Trig\+In\+\_\+\+Pos}}~8U
\item 
\#define \mbox{\hyperlink{group___c_m_s_i_s___c_o_r_e_ga360b413bc5da61f751546a7133c3e4dd}{TPI\+\_\+\+FFCR\+\_\+\+Trig\+In\+\_\+\+Msk}}~(0x1\+UL $<$$<$ \mbox{\hyperlink{group___c_m_s_i_s___c_o_r_e_gaa7ea11ba6ea75b541cd82e185c725b5b}{TPI\+\_\+\+FFCR\+\_\+\+Trig\+In\+\_\+\+Pos}})
\item 
\#define \mbox{\hyperlink{group___c_m_s_i_s___c_o_r_e_gac57b0b588a37a870573560bc6316cbcc}{TPI\+\_\+\+FFCR\+\_\+\+FOn\+Man\+\_\+\+Pos}}~6U
\item 
\#define \mbox{\hyperlink{group___c_m_s_i_s___c_o_r_e_ga7aeb30af62d04e852a55c3bd64c1bd2c}{TPI\+\_\+\+FFCR\+\_\+\+FOn\+Man\+\_\+\+Msk}}~(0x1\+UL $<$$<$ \mbox{\hyperlink{group___c_m_s_i_s___c_o_r_e_gac57b0b588a37a870573560bc6316cbcc}{TPI\+\_\+\+FFCR\+\_\+\+FOn\+Man\+\_\+\+Pos}})
\item 
\#define \mbox{\hyperlink{group___c_m_s_i_s___c_o_r_e_ga9f46cf1a1708575f56d6b827766277f4}{TPI\+\_\+\+DEVID\+\_\+\+NRZVALID\+\_\+\+Pos}}~11U
\item 
\#define \mbox{\hyperlink{group___c_m_s_i_s___c_o_r_e_gacecc8710a8f6a23a7d1d4f5674daf02a}{TPI\+\_\+\+DEVID\+\_\+\+NRZVALID\+\_\+\+Msk}}~(0x1\+UL $<$$<$ \mbox{\hyperlink{group___c_m_s_i_s___c_o_r_e_ga9f46cf1a1708575f56d6b827766277f4}{TPI\+\_\+\+DEVID\+\_\+\+NRZVALID\+\_\+\+Pos}})
\item 
\#define \mbox{\hyperlink{group___c_m_s_i_s___c_o_r_e_ga675534579d9e25477bb38970e3ef973c}{TPI\+\_\+\+DEVID\+\_\+\+MANCVALID\+\_\+\+Pos}}~10U
\item 
\#define \mbox{\hyperlink{group___c_m_s_i_s___c_o_r_e_ga4c3ee4b1a34ad1960a6b2d6e7e0ff942}{TPI\+\_\+\+DEVID\+\_\+\+MANCVALID\+\_\+\+Msk}}~(0x1\+UL $<$$<$ \mbox{\hyperlink{group___c_m_s_i_s___c_o_r_e_ga675534579d9e25477bb38970e3ef973c}{TPI\+\_\+\+DEVID\+\_\+\+MANCVALID\+\_\+\+Pos}})
\item 
\#define \mbox{\hyperlink{group___c_m_s_i_s___c_o_r_e_ga974cccf4c958b4a45cb71c7b5de39b7b}{TPI\+\_\+\+DEVID\+\_\+\+PTINVALID\+\_\+\+Pos}}~9U
\item 
\#define \mbox{\hyperlink{group___c_m_s_i_s___c_o_r_e_ga1ca84d62243e475836bba02516ba6b97}{TPI\+\_\+\+DEVID\+\_\+\+PTINVALID\+\_\+\+Msk}}~(0x1\+UL $<$$<$ \mbox{\hyperlink{group___c_m_s_i_s___c_o_r_e_ga974cccf4c958b4a45cb71c7b5de39b7b}{TPI\+\_\+\+DEVID\+\_\+\+PTINVALID\+\_\+\+Pos}})
\item 
\#define \mbox{\hyperlink{group___c_m_s_i_s___c_o_r_e_ga3c7bb073c7ef96c2c3491c523fcb5bbe}{TPI\+\_\+\+DEVID\+\_\+\+FIFOSZ\+\_\+\+Pos}}~6U
\item 
\#define \mbox{\hyperlink{group___c_m_s_i_s___c_o_r_e_gac7e718d8f239920d5b65e3eaa1c490df}{TPI\+\_\+\+DEVID\+\_\+\+FIFOSZ\+\_\+\+Msk}}~(0x7\+UL $<$$<$ \mbox{\hyperlink{group___c_m_s_i_s___c_o_r_e_ga3c7bb073c7ef96c2c3491c523fcb5bbe}{TPI\+\_\+\+DEVID\+\_\+\+FIFOSZ\+\_\+\+Pos}})
\item 
\#define \mbox{\hyperlink{group___c_m_s_i_s___c_o_r_e_ga0c799ff892af5eb3162d152abc00af7a}{TPI\+\_\+\+DEVTYPE\+\_\+\+Sub\+Type\+\_\+\+Pos}}~4U
\item 
\#define \mbox{\hyperlink{group___c_m_s_i_s___c_o_r_e_ga5b2fd7dddaf5f64855d9c0696acd65c1}{TPI\+\_\+\+DEVTYPE\+\_\+\+Sub\+Type\+\_\+\+Msk}}~(0x\+FUL /\texorpdfstring{$\ast$}{*}$<$$<$ \mbox{\hyperlink{group___c_m_s_i_s___c_o_r_e_ga0c799ff892af5eb3162d152abc00af7a}{TPI\+\_\+\+DEVTYPE\+\_\+\+Sub\+Type\+\_\+\+Pos}}\texorpdfstring{$\ast$}{*}/)
\item 
\#define \mbox{\hyperlink{group___c_m_s_i_s___c_o_r_e_ga69c4892d332755a9f64c1680497cebdd}{TPI\+\_\+\+DEVTYPE\+\_\+\+Major\+Type\+\_\+\+Pos}}~0U
\item
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

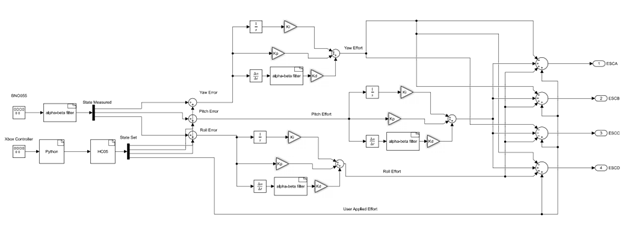
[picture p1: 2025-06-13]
DroneBlockDiagram.png

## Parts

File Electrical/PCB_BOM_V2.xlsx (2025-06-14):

Com+D1+A1+A1:E28 | Designator | Footprint | Package | QTY
0.1 uF | C2, C3, C9, C10, C17, C18, C19 | CAPC1005X60 | 805 | 7
100k | R4 | RESC2012X65 | 0805 | 1
10k | R3, R7, R8, R9, R10, R11, R12 | RESC2012X65 | 0805 | 7
10uF | C1, C6 | CAPC2012X110 | 0805 | 2
10uH | L1 | INDC1006X60N | 1210 | 1
120nF | C14 | CAPC2012X110 | 0805 | 1
13k | R1 | RESC2012X65 | 0805 | 1
15pF | C11, C12 | CAPC2012X110 | 0805 | 2
1uF | C13 | CAPC2012X110 | 0805 | 1
22uF | C4, C5, C7 | CAPC2012X110 | 0805 | 3
39k | R6 | RESC2012X65 | 0805 | 1
4.7uF | C20, C21 | CAPC1005X60 | 805 | 2
51 | R5 | RESC2012X65 | 0805 | 1
691137710002 | J1 | 691137710002 |  | 1
75pF | C8 | CAPC2012X110 | 0805 | 1
8pF | C16, C22 | CAPC1005X60 | 805 | 2
AMS1117-3.3 | U2 | SOT229P700X180-4N |  | 1
BNO055QFN_BNO055_BOS | U3 | QFN_BNO055_BOS |  | 1
ECS-.327-12.5-34B-TR | Y3 | XTAL_ECS-.327-12.5-34B-TR |  | 1
PINHD-1X2 | JP2, JP5 | 1X02 |  | 2
PINHD-1X4 | JP1, JP6 | 1X04 |  | 2
PINHD-1X5 | JP3 | 1X05 |  | 1
PINHD-2X3 | JP7, JP8 | 2X03 |  | 2
PINHD-2X4 | JP4 | 2X04 |  | 1
PMOSFET_SOT23-GSD | Q1 | SOT23 | SOT23 | 1
STM32F411CEU6 | PC13 | QFN50P700X700X55-48N |  | 1
TPS54302DDCR | U1 | SOT95P280X110-6N |  | 1
TS02-66-70-BK-100-LCR-D | S1 | SW_TS02-66-70-BK-100-LCR-D |  | 1
X322516MLB4SI | Y2 | OSC_X322516MLB4SI |  | 1

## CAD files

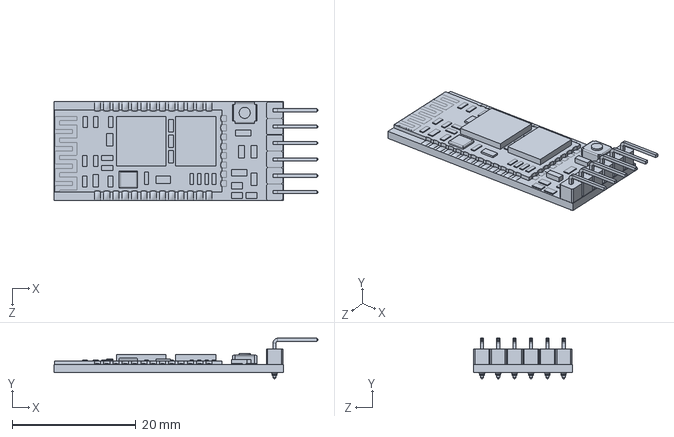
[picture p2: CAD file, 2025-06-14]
Mechanical/HC-05.SLDPRT
42.6 x 6.55 x 16.0 mm

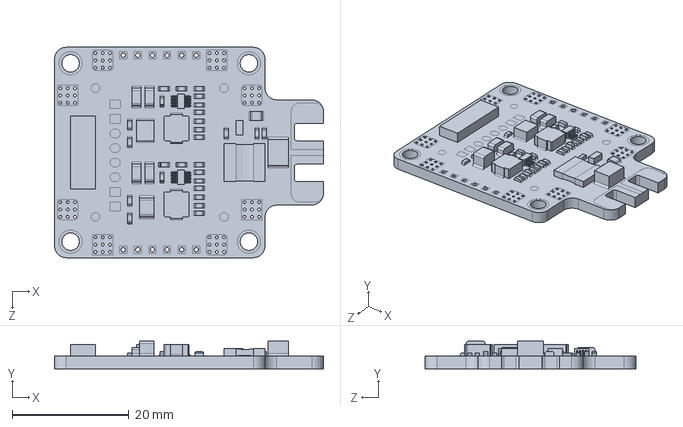
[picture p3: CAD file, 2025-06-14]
Mechanical/PDB.SLDPRT
46.0 x 4.75 x 36.0 mm

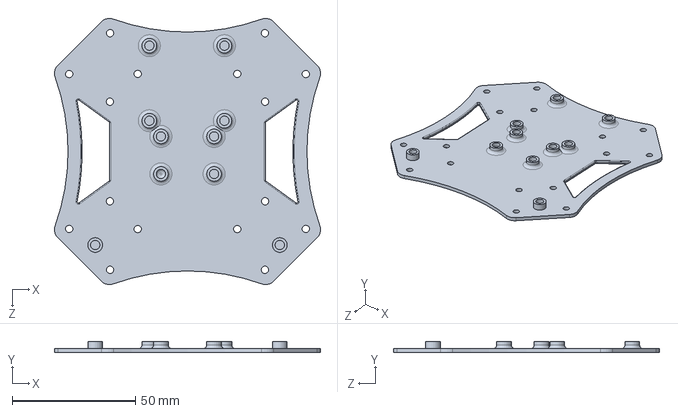
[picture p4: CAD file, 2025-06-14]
Mechanical/Top plate.SLDPRT
108.1 x 4.65 x 108.1 mm

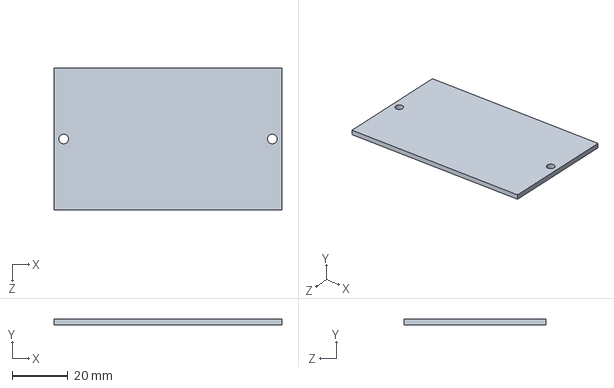
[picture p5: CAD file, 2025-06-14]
Mechanical/BlackPill Proto.SLDPRT
82.0 x 2.00 x 51.0 mm

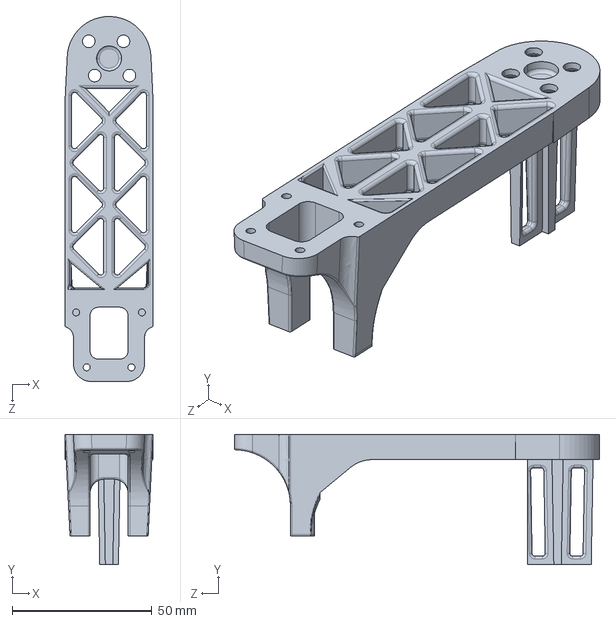
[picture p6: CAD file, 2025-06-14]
Mechanical/DroneArm_V5.STEP
31.5 x 46.5 x 130.5 mm

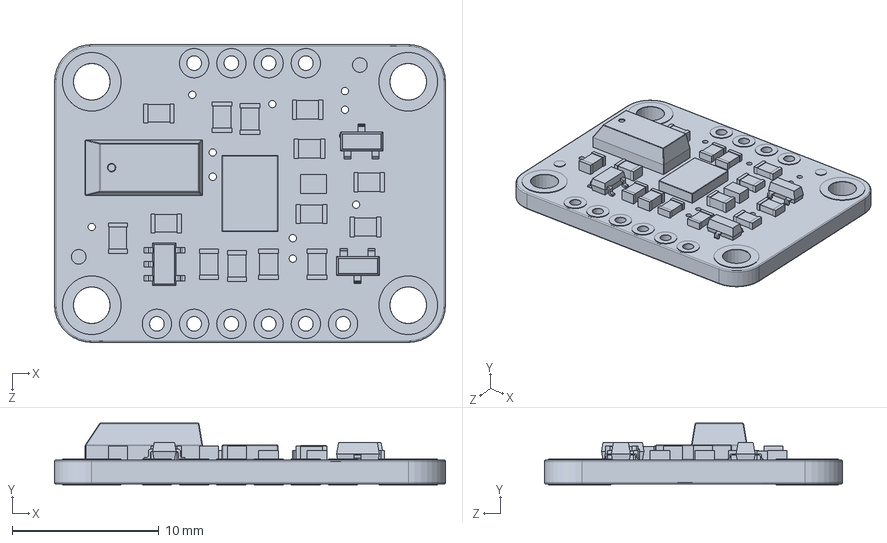
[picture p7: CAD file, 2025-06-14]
Mechanical/Adafruit_BNO055.SLDPRT
26.7 x 4.20 x 20.3 mm

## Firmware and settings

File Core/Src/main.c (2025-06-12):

/**
 * @mainpage Quadcopter Flight Control System
 *
 * @section intro_sec Introduction
 *
 * This is the documentation for a quadcopter design by Aaron Lubisnky and Dane Carroll. This project was taken on and
 * guided by Cal Poly's ME507 course (Graduate Mechanical Control Systems) and instructed by lecturer, Charlie Refvem.
 *
 * The drone has a custom designed and 3D printed frame.
 * It has been designed to operate using a custom PCB including an onboard STM2F411CEU6 MCU and BNO055 IMU. Though,
 * currently uses a Blackpill development board and Bosch BN055 development board due to in house PCB manufacturing failures.
 * The arming sequence is tailored towards ReadyTosky ESCs and the bluetooth module (HC05) is intended to interact with
 * a PC running a custom python script for drone control and plotting blackboc data.
 *
 * @section features_sec Key Features
 *
 * - PID control for roll, pitch, and yaw
 * - BNO055 IMU integration
 * - ESC motor control with safety limits
 * - Flight data logging (blackbox)
 *
 * @section hardware_sec Hardware Requirements
 *
 * - STM32F4 Development Board
 * - BNO055 IMU Module
 * - HC05 Bluetooth Module
 * - 4x Electronic Speed Controllers (ESCs)
 * - 4x 3 Phase Brushless Motors
 * - 4-channel Power Distribution Board
 * - 3s/4s Battery
 * - Status LEDs
 *
 * @section usage_sec Flight Preparation
 *
 * 1. Start program and observe LEDs.
 * 2. Solid Red LED indicates that the BNO055 is calibrating. Maneuver quadcopter in figure-8 pattern until blinking stops LED is calibrated.
 * 3. Use controller to begin arming sequence by pulling left joystick fully to the left. The Red LED should blink at 2Hz.
 * 4. Connect ESCs to battery by switching both mechanical switches. The program will already be applying 100% duty cycle. Wait for audio prompts to cycle.
 * 5. After 4 rapid ESC beeps followed by a single beep. Hold LT on Xbox controller for 5 seconds. This lowers PWM to to complete arming sequence.
 * 6. Once LT is released, wait for another audio prompt (3 beeps, pause, beep). Pull LT fully to the right to begin operational mode.
 * 2. Follow flying instructions until flight concludes. To conclude flight, any of the safety stops will suffice. see section below.
 * 3. If quadcopter no longer in use, unplug battery from power distribution board.
 *
 * @section modules_sec Modules
 *
 * - @ref ESC.c "ESC Driver" - Motor control and PID implementation
 * - @ref BNO055.c "BNO055 Driver" - IMU sensor interface
 * - @ref HC05.c "Bluetooth Driver" = Bluetooth receive and transmit, data parsing
 * * @section flight_instr Flight Instructions
 *  For use only with gaming controller in operational mode
 * - Left Trigger: decrement thrust
 * - Right Trigger: increment thrust
 * - Left Joystick (horizontal): Roll
 * - Left Joystick (vertical): Pitch
 * - Right Joystick (horizontal): decrement/increment Yaw
 *
 * * @section safety_sec Safety Stops
 *
 * - Option 1: Push right joystick fully up on controller
 * - Option 2: Press ENTER on Python Terminal
 * - Option 3: Flip mechanical switches on quadcopter
 *
 * All options will stop motors from spinning and dump 'Blackbox' data to be analyzed through Python Script communicating with the HC05.
 *
 * @author Aaron Lubinsky & Dane Carroll
 * @version 1.4
 * @date 2025
 */




/* USER CODE BEGIN Header */
/**
  ******************************************************************************
  * @file main.c
  * @brief Main program for quadcopter control. derived as FSM mastermind, implemented in pupre C.
  ******************************************************************************
  * @attention
  *
  * Copyright (c) 2025 STMicroelectronics.
  * All rights reserved.
  *
  * This software is licensed under terms that can be found in the LICENSE file
  * in the root directory of this software component.
  * If no LICENSE file comes with this software, it is provided AS-IS.
  *
  ******************************************************************************
  */
/* USER CODE END Header */
/* Includes ------------------------------------------------------------------*/
#include "main.h"

/* USER CODE BEGIN Includes */
#include <unistd.h>
#include <string.h>
#include "BNO055.h"
#include "HC05.h"
#include "ESC.h"

//#include "HC05.h"
/* USER CODE END Includes */

/* USER CODE BEGIN PD */
#define PID_SCALE 100000 //100,000 allow us to use ints, not floats for Kp of 1.1 --> 1,100_000
#define true 1
#define false 0
#define BT_MSG_LEN 37
//#define BT_MSG_LEN 2

/* USER CODE END PD */

I2C_HandleTypeDef hi2c1;
I2C_HandleTypeDef hi2c3;

TIM_HandleTypeDef htim3;

UART_HandleTypeDef huart1;
UART_HandleTypeDef huart2;
DMA_HandleTypeDef hdma_usart2_rx;

/* USER CODE BEGIN PV */
UART_HandleTypeDef *BT_UART_ptr = &huart2;
UART_HandleTypeDef *STLink_UART_ptr = &huart1;
volatile int imu_request = 0;

//State
int state = 0;
int32_t roll_set, pitch_set, yaw_set, effort_set;                // from user control
int32_t roll_true, pitch_true, yaw_true;             // from IMU
int32_t roll_effort, pitch_effort, yaw_effort;
int stopFlag = false; //triggered when effortSet is 0

// PID vars
int32_t roll_integral, pitch_integral, yaw_integral;
int32_t roll_derivative, pitch_derivative, yaw_derivative;
int32_t roll_error, pitch_error, yaw_error;        // error for sample n-1
int32_t last_roll_error, last_pitch_error, last_yaw_error;        // error for sample n-1
int32_t last_last_roll_error, last_last_pitch_error, last_last_yaw_error; // error for sample n-2

// Gains
int32_t K_effort = 50000;
// Roll Axis
int32_t Kp_roll = 450;
int32_t Ki_roll = 30;
int32_t Kd_roll = 120000;
// Pitch Axis
int32_t Kp_pitch = 350;
int32_t Ki_pitch = 40;
int32_t Kd_pitch = 60000;

// Yaw Axis
int32_t Kp_yaw  =0; //Yaw is currently disable
int32_t Ki_yaw = 0; //Yaw is currently disable
int32_t Kd_yaw = 0; //Yaw is currently disable


//BT
uint8_t BT_RxBuf[BT_MSG_LEN]; //This buffer is filled by DMA UART and processed by HC05 driver
int     dumpFlag = 0;  //This flag is triggered by safety stop and tells program to transmit blackbox data

//IMU



//


/* USER CODE END PV */

void SystemClock_Config(void);
static void MX_GPIO_Init(void);
static void MX_DMA_Init(void);
static void MX_I2C1_Init(void);
static void MX_TIM3_Init(void);
static void MX_USART1_UART_Init(void);
static void MX_USART2_UART_Init(void);
static void MX_I2C3_Init(void);
/**
  * @brief  The application entry point.
  * @retval int
  */
int main(void)
{

  /* MCU Configuration--------------------------------------------------------*/

  /* Reset of all peripherals, Initializes the Flash interface and the Systick. */
  HAL_Init();

  /* Configure the system clock */
  SystemClock_Config();

  /* Initialize all configured peripherals */
  MX_GPIO_Init();
  MX_DMA_Init();
  MX_I2C1_Init();
  MX_TIM3_Init();
  MX_USART1_UART_Init();
  MX_USART2_UART_Init();
  MX_I2C3_Init();

  /* Infinite loop */
  /* USER CODE BEGIN WHILE */
  while (1)
  {
	 if (state == 0){
		 BNO_Init(); //initialize BNO055
		 HAL_UART_Receive_DMA(&huart2, BT_RxBuf, BT_MSG_LEN-1); //allow for UART DMA Callback
		 state = 1; //Move to next state

	 }else if (state == 1){ //Arming
		 if (roll_set < -10000){ //Wait for user input (done manually after mechanical switches enabled)
			 armESC(); //begin arming sequence. Leave arming sequence after user input in arming function
			 state = 2; //move to operational state
		 }
		 effort_set = 0; //Safety precaution: eliminates posibility of user mistake: holding accelerate after arming sequence but before start signal

	 }else if(state == 2){ //State 2 is operation (flying) mode where the drone reads the BNO, updates motor PWM to the latest bluetooth DMA
		  BNO_Read(&roll_true, &pitch_true, &yaw_true); //Read BNO, log blackbox data
		  update_Motors(); //PID and update signal
		  if (dumpFlag == 1){ //if user stop detected anywhere
		  			effort_set = 0;
		  			stopFlag = true;
		  			update_Motors();//stop motors
		  			state = 3; //move to dump state
		  		 }


	 }else if(state == 3){//This state is triggered by user input. It sends blackBox data then returns to state 2
		 	dumpBlackbox(); //dump data to HC05
		 	dumpFlag = 0; //reset dumpflag
		 	HAL_UART_Receive_DMA(&huart2, BT_RxBuf, BT_MSG_LEN-1); //reenable UART DMA
		 	while (roll_set < 10000){
		 		//wait for user input
		 	}
		 	state = 2; //ESCs are armed, can return back to state 2
		 	effort_set = 0;
		 	HAL_GPIO_WritePin(GPIOA, GPIO_PIN_1, GPIO_PIN_SET);   // Set PA0 High (go signal)

 }




	  }//while loop close


  //main loop close


    /* USER CODE END WHILE */

}

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
/* USER CODE BEGIN 4 */



/**
  * @brief  This callback function is triggered when UART2 (HC05 Stream) fills BT_RxBuf (Direct to Memory).
  *  It adds an end message statment, sends the buffer to the processInput function and sets the imu_request flag
  *
  * @retval None
  */
void HAL_UART_RxCpltCallback(UART_HandleTypeDef *huart)//should trigger when DMA reads complete message
{    if (huart->Instance == USART2) {
        // Null-terminate just in case you're using sscanf or string functions
        BT_RxBuf[BT_MSG_LEN - 1] = '\0';

        // Process entire message

        processInput((char *)BT_RxBuf, &roll_set, &pitch_set, &yaw_set, &effort_set, &dumpFlag);
        }
        // Restart DMA to receive next message
        //HAL_UART_Receive_DMA(&huart2, BT_RxBuf, BT_MSG_LEN); //set up this function to run on next BT input
        imu_request = true; //set up IMU to run when interupt exits
        HAL_UART_Receive_DMA(&huart2, BT_RxBuf, BT_MSG_LEN-1); //set up this function to run on next BT input
}
/**
  * @brief  This function is used to send printf() statments to the ST-Link UART
  * @retval None
  */
int __io_putchar(int ch) {
    HAL_UART_Transmit(&huart2, (uint8_t *)&ch, 1, HAL_MAX_DELAY);
    return ch;
}
/* USER CODE END 4 */
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


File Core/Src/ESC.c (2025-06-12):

/**
  ******************************************************************************
  * @file    ESC.c
  * @author  Aaron Lubinsky
  * @brief   ESC (Electronic Speed Controller) driver for quadcopter motor control
  * @version 1.0
  * @date    2025
  *
  * @details This driver implements PID-based motor control for a quadcopter ESC system.
  *          It provides functionality to arm ESCs and update motor speeds based on
  *          roll, pitch, and yaw control inputs using PID control algorithms.
  *
  ******************************************************************************
  ==============================================================================
                        ##### How to use this driver #####
  ==============================================================================
  1. Call armESC() to initialize and arm all ESC motors
  2. Call update_Motors() periodically to update motor speeds based on PID control
  3. Ensure all external variables (PID constants, setpoints, etc.) are properly configured

  @note This driver requires STM32 HAL library and Timer 3 configured for PWM output
  @warning Motor safety: Always ensure proper calibration of motor offsets before flight
  */

#include "ESC.h"
#include "stm32f4xx_hal.h"   // Needed for HAL types
#include <stdint.h>
#include <stdio.h>

/* External Timer Handle */
extern TIM_HandleTypeDef htim3; ///< Timer handle for PWM generation (Timer 3)

/* External Control Variables */
extern int effort_set;    ///< Base throttle effort setting (0-1000)
extern int K_effort;      ///< Effort scaling constant
extern int effortRate;    ///< Rate of effort change
extern int stopFlag;

/* External PID Constants */
extern int32_t Kp_roll;   ///< Proportional gain for roll control
extern int32_t Ki_roll;   ///< Integral gain for roll control
extern int32_t Kd_roll;   ///< Derivative gain for roll control
extern int32_t Kp_pitch;  ///< Proportional gain for pitch control
extern int32_t Ki_pitch;  ///< Integral gain for pitch control
extern int32_t Kd_pitch;  ///< Derivative gain for pitch control
extern int32_t Kp_yaw;    ///< Proportional gain for yaw control
extern int32_t Ki_yaw;    ///< Integral gain for yaw control
extern int32_t Kd_yaw;    ///< Derivative gain for yaw control

/* External PID State Variables */
extern int32_t roll_set;        ///< Roll setpoint (desired roll angle)
extern int32_t roll_true;       ///< Current roll angle (from sensors)
extern int32_t roll_error;      ///< Roll error (setpoint - actual)
extern int32_t roll_integral;   ///< Roll integral term accumulator
extern int32_t roll_derivative; ///< Roll derivative term
extern int32_t last_roll_error; ///< Previous roll error for derivative calculation

extern int32_t pitch_set;        ///< Pitch setpoint (desired pitch angle)
extern int32_t pitch_true;       ///< Current pitch angle (from sensors)
extern int32_t pitch_error;      ///< Pitch error (setpoint - actual)
extern int32_t pitch_integral;   ///< Pitch integral term accumulator
extern int32_t pitch_derivative; ///< Pitch derivative term
extern int32_t last_pitch_error; ///< Previous pitch error for derivative calculation

extern int32_t yaw_set;        ///< Yaw setpoint (desired yaw angle)
extern int32_t yaw_true;       ///< Current yaw angle (from sensors)
extern int32_t yaw_error;      ///< Yaw error (setpoint - actual)
extern int32_t yaw_integral;   ///< Yaw integral term accumulator
extern int32_t yaw_derivative; ///< Yaw derivative term
extern int32_t last_yaw_error; ///< Previous yaw error for derivative calculation

extern int32_t roll_effort;  ///< Roll control output effort
extern int32_t pitch_effort; ///< Pitch control output effort
extern int32_t yaw_effort;   ///< Yaw control output effort

/**
 * @brief PID scaling factor for fixed-point arithmetic
 * @details Used to maintain precision in PID calculations while using integer math
 */
#define PID_SCALE 100000

/**
 * @brief Motor offset calibration values
 * @details These offsets compensate for individual motor/ESC variations
 * @{
 */
int motA_offset = 960; ///< Motor A PWM offset (front-right motor)
int motB_offset = 960; ///< Motor B PWM offset (rear-right motor)
int motC_offset = 960; ///< Motor C PWM offset (rear-left motor)
int motD_offset = 960; ///< Motor D PWM offset (front-left motor)
/** @} */

/**
 * @brief Motor PWM compare values
 * @details Individual motor PWM compare values sent to timer
 * @{
 */
int A = 0; ///< Motor A PWM compare value
int B = 0; ///< Motor B PWM compare value
int C = 0; ///< Motor C PWM compare value
int D = 0; ///< Motor D PWM compare value
/** @} */

int armCompare = 0;     ///< PWM compare value used during ESC arming sequence
int max_integral = 400000; ///< Maximum integral windup limit


// Add these global variables for rolling average derivative calculation

#define DERIVATIVE_SAMPLES 20

// Rolling average arrays for each axis (no index needed)
int roll_delta_history[DERIVATIVE_SAMPLES] = {0};
int pitch_delta_history[DERIVATIVE_SAMPLES] = {0};
int yaw_delta_history[DERIVATIVE_SAMPLES] = {0};

/**
 * @brief Arms all ESC motors by sending initialization sequence
 *
 * @details This function sends the proper PWM signals to arm all four ESC motors.
 *          It starts PWM generation on all channels and sends a specific pulse width
 *          (approximately 1000μs) to arm the ESCs. The function continues until
 *          the roll_set value reaches a threshold, indicating the system is ready.
 *
 * @note This function blocks execution until arming is complete
 * @warning Ensure motors are properly secured before calling this function
 *
 * @see update_Motors()
 */
void armESC()
{
    effort_set = 1000;

    while(roll_set < 10000){
        // Start PWM generation on all timer channels
        HAL_TIM_PWM_Start(&htim3, TIM_CHANNEL_1);
        HAL_TIM_PWM_Start(&htim3, TIM_CHANNEL_2);
        HAL_TIM_PWM_Start(&htim3, TIM_CHANNEL_3);
        HAL_TIM_PWM_Start(&htim3, TIM_CHANNEL_4);

        // Calculate arming PWM value (approximately 1000μs pulse width)
        armCompare = effort_set*4 - 2000;

        // Clamp arming value to safe range
        if (armCompare < 960) armCompare = 960;
        if (armCompare > 2000) armCompare = 2000;

        // Set PWM compare values for all motors
        __HAL_TIM_SET_COMPARE(&htim3, TIM_CHANNEL_1, armCompare);
        __HAL_TIM_SET_COMPARE(&htim3, TIM_CHANNEL_2, armCompare);
        __HAL_TIM_SET_COMPARE(&htim3, TIM_CHANNEL_3, armCompare);
        __HAL_TIM_SET_COMPARE(&htim3, TIM_CHANNEL_4, armCompare);

        // Toggle status LED during arming
        HAL_GPIO_TogglePin(GPIOA, GPIO_PIN_0);
        HAL_Delay(125);
    }

    // Reset effort and compare values after arming
    effort_set = 0;
    armCompare = 0;
}
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
